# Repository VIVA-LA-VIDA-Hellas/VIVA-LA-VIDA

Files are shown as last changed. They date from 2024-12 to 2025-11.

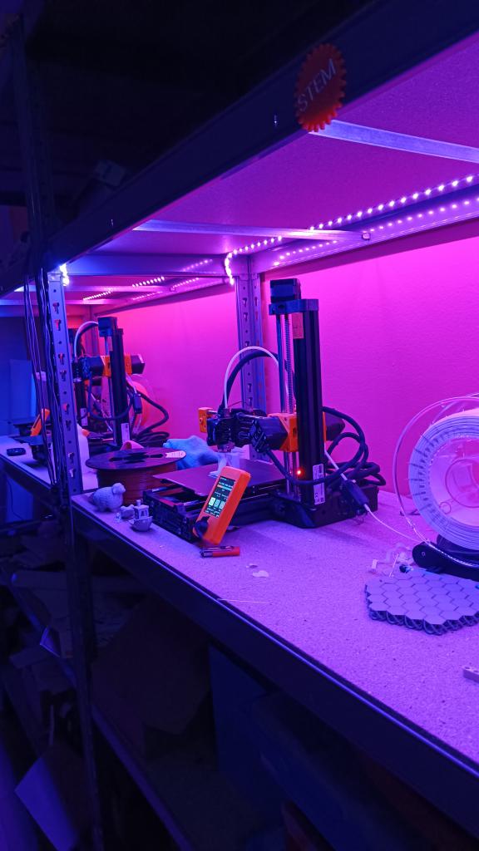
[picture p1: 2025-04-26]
3d designs/3d printed part photos/3d printing process.jpg

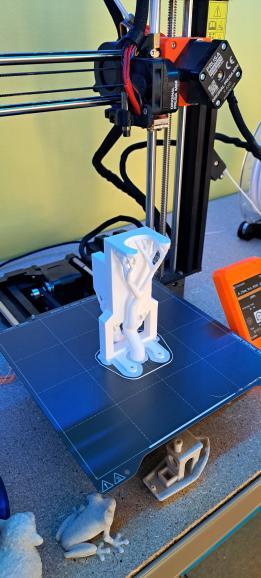
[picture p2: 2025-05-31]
3d designs/3d printed part photos/Motor base printing.jpg

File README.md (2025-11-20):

# **VIVA ΛA VIΔA** 
# $${\color{green}FUTURE \space ENGINEERS \space 2025}$$ 
> ## HELLENIC TEAM

viva la vida gif

## <ins>*Find us on:*<ins/>
Website (https://www.viva-la-vida.gr/)
Youtube (https://www.youtube.com/@VIVALAVIDAFutureEnginners)
Facebook (https://www.facebook.com/groups/1252558666360750)
Instagram (https://www.instagram.com/viva_la_vida_gr/)
TikTok (https://www.tiktok.com/@viva_la_vida_gr)

## TEAM MEMBERS:
### Nikol Vasilopoulou (user: Quart0xe)
### Panagiotis Mourmouris (user: Panos1431)
### Thanos Karatsis (user: thkaratsis)

*Disclaimer: we did not use these accounts in the creation of this repository. Instead we created a new email and github account specificaly for our team, which we all have access to and utilise across all platforms. 

# INDEX
### *Use the index for an easy navigation of our github or, continue bellow to view our creation process, as well as an overview on everything about the robot.*

## 1. Mobility management
####        1.1 [Motor](https://github.com/VIVA-LA-VIDA-Hellas/VIVA-LA-VIDA/blob/main/Vehicle/Compartments/Electronics-DC-Motor.md)
####        1.2 [Ackerman](https://github.com/VIVA-LA-VIDA-Hellas/VIVA-LA-VIDA/blob/main/Vehicle/Compartments/Ackerman%20Steering.md)
####        1.3 [Servo](https://github.com/VIVA-LA-VIDA-Hellas/VIVA-LA-VIDA/blob/main/Vehicle/Compartments/Electronics-Servo-Motor.md)
####        1.4 [Servo and motor 3d Bases](https://github.com/VIVA-LA-VIDA-Hellas/VIVA-LA-VIDA/tree/main/3d%20designs/3d%20schematics)

## 2. Power Management
####        2.1 [Batteries](https://github.com/VIVA-LA-VIDA-Hellas/VIVA-LA-VIDA/blob/main/Vehicle/Compartments/Electronics-Power%20System.md)
####        2.2 [PCB circuit designs and schematics](https://github.com/VIVA-LA-VIDA-Hellas/VIVA-LA-VIDA/tree/main/Schematics/PCB)

## 3. Sensors
####        2.1 [Distance sensors](https://github.com/VIVA-LA-VIDA-Hellas/VIVA-LA-VIDA/blob/main/Vehicle/Compartments/Electronics-Sensors-Distance.md)
####        2.2 [Accelerometre / Gyro](https://github.com/VIVA-LA-VIDA-Hellas/VIVA-LA-VIDA/blob/main/Vehicle/Compartments/Electronics-Sensors-Gyro.md)
####        2.3 [Camera](https://github.com/VIVA-LA-VIDA-Hellas/VIVA-LA-VIDA/blob/main/Vehicle/Compartments/Electronics-Camera.md)
####        2.4 [Buttons & Leds](https://github.com/VIVA-LA-VIDA-Hellas/VIVA-LA-VIDA/blob/main/Vehicle/Compartments/Electronics-Interface-and-Debugging.md)

## 4. 3D Prints
####        4.1 [3D schematics](https://github.com/VIVA-LA-VIDA-Hellas/VIVA-LA-VIDA/tree/main/3d%20designs/3d%20schematics)
####        4.2 [Photos of 3D printed parts](https://github.com/VIVA-LA-VIDA-Hellas/VIVA-LA-VIDA/tree/main/3d%20designs/3d%20printed%20part%20photos)

## 5. Pictures 
####        5.1 [Team photos](https://github.com/VIVA-LA-VIDA-Hellas/VIVA-LA-VIDA/tree/main/Team%20photos)
####        5.2 [Vehicle photographs](https://github.com/VIVA-LA-VIDA-Hellas/VIVA-LA-VIDA/tree/main/Robot%20Photos)

## 6. Performance videos
####        6.1 [Youtube channel link](https://www.youtube.com/@VIVALAVIDAFutureEnginners)
####        6.2 [All video links](https://github.com/VIVA-LA-VIDA-Hellas/VIVA-LA-VIDA/tree/main/Videos)

## 7. Daily entries
####        7.1 [Logs](https://github.com/VIVA-LA-VIDA-Hellas/VIVA-LA-VIDA/tree/main/Training%20meetings%20log)

## 8. Code files
####        8.1 [Open Challenge](https://github.com/VIVA-LA-VIDA-Hellas/VIVA-LA-VIDA/tree/main/Code%20files/1.%20Open%20Challenge)
####        8.2 [Obstacle Challenge](https://github.com/VIVA-LA-VIDA-Hellas/VIVA-LA-VIDA/tree/main/Code%20files/2.%20Obstacle%20challenge)
####        8.3 [Colour Calibration](https://github.com/VIVA-LA-VIDA-Hellas/VIVA-LA-VIDA/blob/main/Code%20files/Python%20files/New%20files%20September%2B/Colour_picker.py)

## 9. Manuals
####        9.1 [Instruction manuals](https://github.com/VIVA-LA-VIDA-Hellas/VIVA-LA-VIDA/tree/main/Instruction%20Manuals)
####        9.2 [Lego ackerman instructions](https://github.com/VIVA-LA-VIDA-Hellas/VIVA-LA-VIDA/tree/main/Instruction%20Manuals/Lego%20ackerman%20instructions)
####        9.3 [Lego differential instructions](https://github.com/VIVA-LA-VIDA-Hellas/VIVA-LA-VIDA/tree/main/Instruction%20Manuals/Lego%20differential%20instructions)
####        9.4 [Build details](https://github.com/VIVA-LA-VIDA-Hellas/VIVA-LA-VIDA/tree/main/Robot%20Photos/Descriptive%20photos)
####        9.5 [Full instructions](https://github.com/VIVA-LA-VIDA-Hellas/VIVA-LA-VIDA/tree/main/Instruction%20Manuals/Full%20robot%20instructions)

## 10. Extra material
####        10.1 [Team logo](https://github.com/VIVA-LA-VIDA-Hellas/VIVA-LA-VIDA/tree/main/Team%20-%20Extras/Logo)
####        10.2 [Team name - VIVA ΛΑ VIΔΑ](https://github.com/VIVA-LA-VIDA-Hellas/VIVA-LA-VIDA/tree/main/Team%20-%20Extras/Name)
####        10.3 [Team shirts](https://github.com/VIVA-LA-VIDA-Hellas/VIVA-LA-VIDA/tree/main/Team%20-%20Extras/Shirts)

# RESEARCH / EXPERIMENTAL PHASE

### Creating [red/green colour detection](https://github.com/VIVA-LA-VIDA-Hellas/VIVA-LA-VIDA/blob/main/Code%20files/Python%20files/R_G_cannyoutlineWORKING.py)
Using python and opencv we created a program that detects red and green objects and outputs what the computer sees in the prossess.
To do this, firstly we used colour dropping to <ins> find approximate HSV values  of obstacles and edit the ranges in our code </ins>

### $${\color{red}Red:}$$



### $${\color{green}Green:}$$



### [Colour picker used](https://pinetools.com/image-color-picker)

Using the data, we created a range where an object is detected as red or green. The full range that can be detected is min:0 , max:255
```python
    red_lower = np.array([0, 120, 70])
    red_upper = np.array([10, 255, 255])
```
```python
    green_lower = np.array([45, 160, 0])
    green_upper = np.array([100, 255, 150])
```
Then, we applied a HSV mask to separate the objects of each colour from the rest of the feed and used imgcanny to find the corners of the objects detected, using that to add an outline according to their colour (red/green)
Mask:
```python
mask_red1 = cv2.inRange(imgHSV, red_lower, red_upper)
```
Outline:
```python
    img_contours = img.copy()
    for contour in contours_red:
        x, y, w, h = cv2.boundingRect(contour)
        cv2.rectangle(img_contours, (x, y), (x + w, y + h), (0, 0, 255), 2)  # Red rectangle
```
Same for green.
> ### Green:


> ### Red:



Notice how it even detects the pile of red objects on the floor **~3m away**, We want to turn based on the closest object to the robot at any given time.
To detect that, we add limits to the size we consider an object 
> We do this so that it doesnt start turning too early or if it sees a spec of green/red in the background), its basically a filtering process that cuts down on most of the >noise.

For trials we set the minimum requirement in size (area) for a detected colour mass to be considered an object, as **500 pixels**
```python
def get_largest_contour(mask, min_area=500)
```

Next, we made it choose the largest object visible to focus on first
```python
def get_largest_contour(mask, min_area=500):
    contours, _ = cv2.findContours(mask, cv2.RETR_EXTERNAL, cv2.CHAIN_APPROX_SIMPLE)
    if not contours: return None
    largest = max(contours, key=cv2.contourArea)
    if cv2.contourArea(largest) < min_area: return None
    x, y, w, h = cv2.boundingRect(largest)
    return largest, (x, y), (x + w, y + h), w*h
```

### Updating our colour picking method
The issue with this code was that it needed calibrating in different lighting conditions, so we made out own [colour picker](https://github.com/VIVA-LA-VIDA-Hellas/VIVA-LA-VIDA/blob/main/Code%20files/Python%20files/New%20files%20September%2B/Colour_picker.py) that worked more accurately with the hsv values our camera detected. With this the obstacle detection became much more time efficient but also accurate.

Colour picker sample
```python
def mouse_callback(event, x, y, flags, param):
    global frame
    if event == cv2.EVENT_LBUTTONDOWN and frame is not None:
        bgr = frame[y, x]
        hsv = cv2.cvtColor(np.uint8([[bgr]]), cv2.COLOR_BGR2HSV)[0][0]
        print(f"Clicked at ({x},{y}) | BGR: {bgr} | HSV: {hsv}")

cv2.namedWindow("Live Feed")
cv2.setMouseCallback("Live Feed", mouse_callback)
```
We use input from our camera to our computer as a live feed, clicking on any pixel to get the HSV values the camera detects straight to our terminal.
We can then imput them straight into our colour detection limits, (red_lower, red_upper, green_lower, green_upper)

### Using what we detected to avoid the obstacles
Now that we can succesfully detect the red and green obstacles, we decided to implement a simple system for the robot to use in order to turn. 
It uses the Objects detected as a reference point and tries to rotate away from them, untill they are outside of the visible area (in other words, when they are far away enough for the robot to not collide with them).
Reminder, the robot must move **right** if it detects **red** and on the flip side, **left** when it detects **green**
> In other words, if we draw a line on the right side of the "turn right" block (red) and the left side of the "turn left" block (green), by moving toward the side it is placed on and effectively moving the entire obstacle out of our view, we manage to pass it.

So for **Green** (Turn left):

green pillar

And for **Right** (Turn right):

red pillar

### Next, we created the [Middle_Lane_Canny](https://github.com/VIVA-LA-VIDA-Hellas/VIVA-LA-VIDA/blob/main/Code%20files/Python%20files/Middle_Lane_Canny_WORKING.py)
We applied the same code from the previous program, this time switching green and red with white and black in order to diffrentiate the (white) floor from the (black) walls.
From this process, instead of outlining the walls found, we used the line they formed from edge detection on each side and <ins> calculated the middle point between the two to create a path for the robot to follow </ins>
```python
for i in range(height):
        left_avg = left_edges[i]
        right_avg = right_edges[i]

        if left_avg is not None and right_avg is not None:
            # Calculate the midpoint and draw the path
            middle_line = (left_avg + right_avg) // 2

            # Draw the path line (white) with increased thickness
            cv2.line(edges_black, (middle_line, i), (middle_line, i), (255, 255, 255), 3)  # Increased thickness
```

[You can see the output we got here](https://github.com/VIVA-LA-VIDA-Hellas/VIVA-LA-VIDA/blob/main/Videos/MIDDLE_LANE_VIDEO_COMPRESSED.mp4)

### Output image

### When we moved the inner square walls, <ins>the path to follow (middle lane) moved too</ins>


### Why we didn't end up using this code (Middle_Lane_Canny) for the first mission
Although this code worked exceptionally well when the robot was faced with long straight paths surrounded by contrasting walls, the same can't be said for turns.
When we tested it with a large camera connected to a laptop, it was facing the track from a very high up angle so it had a better view and could detect turns well.
But, when we tested multiple different cameras connected to a raspberry pi, including a fisheye camera, none of them has a scope wide enough for the current code to predict sharp turns, so the path ended up either guiding the robot straight into the wall, or, turning the opposite direction than expected.  

This wasnt working for us. The camera couldn't be as high up as it was originally when its placed on the robot -in the track- and it also needed the robot to go relatively slow so it can catch up with the camera feedback. This is fine for the second mission, where obstacle avoidance is a higher priority than speed, but for a quick first mission we had to find a new way to sense when and how much the car needs to turn.

>[!NOTE]
>The fact that this detection process didn't work for us doesn't render it unuseable. Combined with the use of a different logic specifically for turns, there is potential for a useable output but we decided to take a different approach.

### Recognising turns - Detecting Blue and Orange lines
Using the same colour picking process we created earlier, we can also detect blue and orange. Using these colours we were able to turn as well as the direction of said turn.

Example values:
## $${\color{blue}Blue}$$
```python
    blue_lower = np.array([100, 60, 80])
    blue_upper = np.array([120, 120, 170])
    mask_blue = cv2.inRange(imgHSV, blue_lower, blue_upper)
```
## $${\color{orange}Orange}$$
```python
    orange_lower = np.array([0, 110, 110])
    orange_upper = np.array([20, 160, 230])
    mask_orange = cv2.inRange(imgHSV, orange_lower, orange_upper)
```

Of course, these values have to be calibrated before the launch of every mission due to the changes in lighting conditions, but we found that this process was much more failproof so it was utilised for the second mission.

The logic of the [Blue and Orange turn detection](https://github.com/VIVA-LA-VIDA-Hellas/VIVA-LA-VIDA/blob/main/Code%20files/Python%20files/New%20files%20September%2B/Stage%202/Orange%20Blue%20detection.py) Program is as follows:

Using the HSV mask, this time with blue and orange instead of red and green, we detect the presense of those colours in the feed.
The difference between the detection comes with the shape of what we're trying to detect. Instead of the cube shaped obstacles that were being previously detected as squares, we needed to now detect lines - continuous strings of pixels with either colour.

 We detected the lines using Hough Transform
 ```python
    lines_orange = cv2.HoughLinesP(edges_orange, 1, np.pi / 180, threshold=50, minLineLength=50, maxLineGap=10)
    lines_blue = cv2.HoughLinesP(edges_blue, 1, np.pi / 180, threshold=50, minLineLength=50, maxLineGap=10)

    img_lines = img.copy()

    # Draw lines for visualization
    if lines_orange is not None:
        for x1, y1, x2, y2 in lines_orange[:, 0]:
            cv2.line(img_lines, (x1, y1), (x2, y2), (255, 0, 0), 2)

    if lines_blue is not None:
        for x1, y1, x2, y2 in lines_blue[:, 0]:
            cv2.line(img_lines, (x1, y1), (x2, y2), (0, 165, 255), 2)
 ```
We needed to track which of the two lines (If they were visible) was closest to the robot.
Since the camera output is in 2d, the **depth** that we see is changed into **height**.

<p align="center" width="100%">
    From our angle vs from the robots point of view: 
</p>
<p align="center" width="100%">
     
     
</p>

<p align="center" width="100%">
    From the robot's perpective, the line that is closer to it is also <ins> the line that appears lower on its y axis. </ins>
     
</p>

As you can see in the above image, in this specific scenario where the orange line is clearly closer than the blue one, it is also lower at the point where it intersects with the y axis.
We utilised this property in our code, but instead of using the point y=0 (midpoint) as reference, we used the pixels of our camera output.
Since when we start out camera configuration, we always set it to:

```python
picam2 = Picamera2()
picam2.configure(picam2.create_preview_configuration(main={"size": (640, 480)}))
picam2.start()  
```
So, a total of 640 pixels on the y axis and 480 on the x axis,
>[!NOTE]
>The values start at the top-left most corner where (x,y) is (0,0), Therefore when an object is detected at (example) (x,600), it is at the bottom of the screen.
>Since we want the object to be close to the robot when it turns to avoid turning too early, we set a reference point of y=400 to act as a "secondary x axis", where if orange/blue is detected above that limit (so, on the lower third of the screen), the car should turn.

For safety, we also implemented a condition to eliminate the chanse of both a orange and blue line simulatiously being found bellow the threshold, where the robot only takes into account the one which is closest to itself.

```python
        orange_y = 0
        blue_y = 0
        orange_y = y_at_center(lines_orange)
        blue_y = y_at_center(lines_blue)
 ```

*The values of orange_y and blue_y are originally set to 0 to avoid an error we encountered where the lower line was detected bellow the threshold before the further one was detected at all, returning a non valid value ("NONE") and ending the program abruptly.

```python
        if orange_y > blue_y and orange_y > 400:
            print("Turn right (orange line lower at center)")
            Turn = "Right"
            TURN_ANGLE = 120
        elif blue_y > orange_y and blue_y > 400:
            print("Turn left (blue line lower at center)")
            Turn = "Left"
            TURN_ANGLE = 60
        else:
            print("No line detected at center")
            Turn = "No"
```

Using the above logic combined with an IMU for turning, we managed to make our [imucameraturn.py](https://github.com/VIVA-LA-VIDA-Hellas/VIVA-LA-VIDA/blob/main/Code%20files/Python%20files/New%20files%20September%2B/Stage%202/imucameraturn.py) program.
> ## A program that:
> Moves forward until either a blue or orange line is detected
> Depending on which one is a) lower and b) bellow our set threshold of 400 pixels, output the turn direction (left or right)
> Steer untill the IMU detects the 90 degree change, by setting the servo angle to point left or right accordingly.

This straight-forward logic was ready to be implemented in the trials for the **second mission.**

# First mission - Final programm description

<!-- TOC -->
- [Project Overview](#project-overview)
- [Core Functionality](#core-functionality)
- [Control Logic (high level)](#control-logic-high-level)
- [Code Structure](#code-structure)
- [Hardware Setup](#hardware-setup)
- [Configuration](#configuration)
- [System Architecture Diagram](#system-architecture-diagram)
- [Mission Path Diagram](#mission-path-diagram)
<!-- /TOC -->

The program runs on a **Raspberry Pi** and offers two operation modes:
- **GUI Mode (Debug):** Visual interface with real-time plots and tuning sliders.
- **Headless Mode (Competition):** Fully autonomous execution via physical start button.

---

## Core Functionality 
- **Autonomous Navigation:**
  - Follows walls using ToF (VL53L0X) or Ultrasonic sensors.
  - Performs left/right turns based on open-space detection and front thresholds.

- **Finite-State Machine Logic:**
  - Operates under these main states:  
    `IDLE → CRUISE → TURN_INIT → TURNING → POST_TURN → STOPPED`
  - Each state manages specific motor and servo behaviors.

- **Sensor Fusion & Filtering:**
  - Combines ToF/ultrasonic inputs using median, spike rejection, and optional EMA smoothing.
  - Stabilizes readings and eliminates transient noise.

- **Yaw & Turn Control:**
  - Integrates MPU6050 gyro data for angular tracking.
  - Executes precision turns with direction locking, timeouts, and slew-limited servo control.

- **Adaptive Environment Handling:**
  - Detects narrow corridors via side-sum analysis.
  - Dynamically scales speed and correction margins for safer movement.

- **Safety & Lap Control:**
  - Instant front-stop and obstacle recheck timer.
  - Lap counting with automatic halt after the final lap.

---

## Control Logic (high level) 
- **CRUISE:** Straight motion; after 1st turn, apply timed wall-following corrections if side distance < soft margin.
- **TURN_INIT:** When `front < FRONT_TURN_TRIGGER` and lockout OK; keep straight (or gentle correction after 1st turn) while waiting for **exactly one** open side. Apply optional **direction lock** after the first decision.
- **TURNING:** Set servo to the commanded (left/right) angle; integrate gyro Z and **stop when target yaw** is reached within tolerance. Guards: timeout and max yaw.
- **POST_TURN:** Short straight stretch to stabilize, then return to CRUISE.
- **STOPPED:** Triggered by obstacle or max-laps; obstacle mode self‑retries after a wait window.

**Narrow Mode:** If `left+right` (valid readings) < threshold, scale speeds/thresholds to be conservative in tight corridors.

---

## Code Structure 

1. Imports
    - External Libraries
    - Internal Modules
2. Variables
    - Global Constants
    - Robot-Specific Variables
3. H/W Setup
    - Hardware Configuration
    - Pin Assignments
4. Robot Classes
    - Sensor Handling
    - Motor Control
    - State Management
5. Robot Loop
    - Main Control Loop
    - Decision Making
    - Movement Logic
6. GUI
    - Tkinter Setup
    - Sliders & Data Visualization
7. Main
    - Initialization
    - Robot Execution
      
---

## Hardware Setup 
| Component | Function |
|---|---|
| Raspberry Pi | Core computing unit |
| PCA9685 | Motor and servo PWM driver |
| VL53L0X ToF Sensors | Distance measurement |
| Ultrasonic Sensors | Alternative wall sensing |
| MPU6050 | Gyro for yaw tracking |
| LEDs | Status indication |
| Button | Start trigger in headless mode |

---

## Configuration 
Configuration values are defined in code but can be overridden using `1st_mission_variables.json`.
All GUI slider changes can be saved and reloaded.

---

## System Architecture Diagram 
```text
 ┌──────────────────────────────────────────┐
 │             SENSOR THREAD                │
 │  - ToF & Ultrasonic readings             │
 │  - Median & EMA filtering                │
 │  - Updates global sensor_data            │
 └──────────────────────────────────────────┘
                    │
                    ▼
 ┌──────────────────────────────────────────┐
 │            ROBOT LOOP (FSM)              │
 │  IDLE → CRUISE → TURN_INIT → TURNING →   │
 │  POST_TURN → STOPPED                     │
 │  - Yaw integration (MPU6050)             │
 │  - Servo & motor control                 │
 │  - Lap counting & safety                 │
 └──────────────────────────────────────────┘
                    │
                    ▼
 ┌──────────────────────────────────────────┐
 │             GUI / HEADLESS MODE          │
 │  - Dashboard                             │
 │  - Sliders, plots, and CSV export        │
 │  - Physical start button (headless)      │
 └──────────────────────────────────────────┘
```

---

## Run Modes 
- **Debugging (GUI) Mode:**
  Set `USE_GUI = 1` and press Start Readings & Start Loop button.
- **Competition (Headless) Mode:**
  Set `USE_GUI = 0` and press the hardware start button.

---

# BOM Bill of materials all prices for our robot compartments

## Core System
| Material | Amount | Price  |
|---|---|---|
| Raspberry Pi 5 8GB | 1 | 96.50 |
| Raspberry Pi Micro SD 64GB | 1 | 9.50  |
| Active Cooler for Raspberry Pi 5 | 1 | 6.40  |
| GPIO Ribbon Cable 40P | 1 | 2.00  |
| IDC Connector 2x20 Pin Male | 1 | 0.45  |

## Sensors
| Material | Amount | Price |
|---|---|---|
| Camera Arducam IMX219 fisheye lens | 1 | 18.92 |
| Ultrasonic Sensor HC-SR04 | 3 | 5.40  |
| Laser Sensor - VL53L0X | 6 | 28.80 |
| Triple Axis Gyroscope & Accelerometer MPU6050 | 1 | 3.60  |

## Power & Protection
| Material | Amount | Price |
|---|---|---|
| Battery Holder 1x18650 for PCB | 3 | 2.70  |
| Battery Lithium 18650 3.6V 3400mAh | 3 | 17.40 |
| Li-ion Battery Charger Protection Board | 1 | 3.40  |
| Fuse 4A | 1 | 0.71  |
| Main Power Switch | 1 | 2.23  |
| DC Power Jack 5.5×2.1mm | 1 | 0.20  |
| Step-Down Converter LM2596S | 1 | 2.90  |

## Motors & Motion
| Material | Amount | Price |
|---|---|---|
| Metal Gearmotor 25mm – 210RPM 9–12V | 1 | 6.80  |
| DC Motor Driver Board DRV8871 | 1 | 10.80 |
| Standard Servo MG996R | 1 | 8.90  |
| 16-Channel PWM/Servo Driver PCA9685 | 1 | 6.80  |

## Wiring & Connectors
| Material | Amount | Price |
|---|---|---|
| Jumper Wires 30cm 5-Pin | 6 | 2.50  |
| Molex KF2510 Jumper Wire 4-Pin | 3 | 1.20  |
| Flexible Flat Cable 0.5mm 22-Pin | 1 | 2.90  |

## PCB & Prototyping
| Material | Amount | Price |
|---|---|---|
| PCB Prototype | 5 | 26.25 |
| Tact Switch SMD | 1 | 0.08  |
| LED 0805 SMD | 3 | 0.36  |
| Resistor 0805 | 12 | 0.24  |

## Fasteners & Hardware
| Material | Amount | Price |
|---|---|---|
| M2 Plastic F/F L20mm | 2 | 0.30  |
| M2×8mm | 8 | 0.47  |
| M3×12mm Flat Head | 2 | 0.11  |
| M3×16mm Flat Head | 20 | 1.15  |
| M3×20mm Flat Head | 14 | 0.97  |
| M3×30mm Flat Head | 2 | 0.15  |
| M3×50mm | 2 | 0.70  |

##  [Complete list of all materials amounts and prices](https://github.com/VIVA-LA-VIDA-Hellas/VIVA-LA-VIDA/blob/main/Instruction%20Manuals/Materials%20needed%20and%20BOM.md)

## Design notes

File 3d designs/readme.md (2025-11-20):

# INSTRUCTIONS - HOW TO ASSEMBLE THE 3D PRINTED MECHANICAL PARTS FROM SCRATCH

## OVERVIEW

  How were the 3D-printed parts designed?
  What tools are needed for the process? 
  How can the car be assembled step by step?

## DESIGN OF 3D PARTS

All the 3D-printed components of the car were designed using Fusion 360, a powerful software that allows us precise modeling of every detail.



Throughout the development process, each part was refined repeatedly, with multiple design
iterations made to enhance efficiency, performance, and overall assembly compatibility.
This continuous cycle of testing and improvement ensured that every printed element met
the project’s functional requirements while maintaining structural integrity.

In the following photo you can see an overview of the creation process of the motorbase throughout our versioning.



Making changes to the original sketches was an essential part of achieving both efficiency and precision in the final design.
Each adjustment, whether in dimensions, geometry, or alignment, contributed to improving how the parts fit and functioned together.
These refinements not only reduced material waste and printing time but also ensured smoother assembly and more reliable performance during the car’s missions.
Through this iterative process, the design evolved from a basic concept into a well-optimized model capable of delivering consistent and accurate results.





After a series of careful modifications and refinements, the final model demonstrates an optimal balance between design accuracy and functional performance.
Each individual change, however small, contributed to a more efficient structure and smoother operation, ensuring that every component works seamlessly as part of the whole.
The result is a precisely engineered model car that fulfills its intended missions with reliability and efficiency, reflecting the success of a thoughtful and well-executed design process.

## TOOLS AND EQUIPEMENT

Using 3D printers to produce the car’s components was a logical and efficient choice, given the need for precision, customization, and consistency across all parts.
It also helps us by eliminating the need for expensive replacements in the scenario of a broken part, since we can easily print a replica at a fraction of the cost.
Additive manufacturing allowed each piece to be fabricated directly from the digital design, ensuring exact dimensions and reducing the possibility of human error.
This method also made it possible to create complex geometries that would be difficult to achieve through traditional manufacturing, while maintaining full control over material usage and production time.

> [!NOTE]
> The printers primarily used for this project were the Prusa i3 MK3S and the Prusa Mini, both known for their reliability, accuracy, and high-quality output.

6n7

To assemble the individual 3D-printed components, a combination of **screws** and **nuts** was used to ensure durable and stable connections between parts.
The assembly required the use of various hand tools, including
>
> Precision screwdrivers
>
> Allen keys
>
> Small wrenches
>
> Pliers
>
> Rulers, Measuring tapes and other measuring tools

which allowed for accurate alignment and secure fastening without damaging the printed surfaces.
This method provided both strength and flexibility, enabling easy disassembly for maintenance or adjustments when needed.
Additionally, a few small modular elements (LEGO Components) were incorporated into certain sections,
adding an extra layer of versatility and precision to the overall construction.



In addition to the main 3D-printed and mechanical components, several secondary materials 
such as **rubber bands** and **small springs** were incorporated to enhance the car’s overall stability and efficiency.
These elements played a crucial role in absorbing vibrations, maintaining tension where needed, and ensuring smoother movement during operation.
Though simple in nature, these materials contributed significantly to the model’s performance,
providing flexibility and resilience that complemented the precision of the printed and assembled parts.




# $${\color{green}INSTRUCTIONS}$$	    

## $${\color{lightgreen}How \space to \space succesfully \space replicate \space our \space robots \space 3d \space printed \space compartments}$$

## Step 1: Prepare Your 3D Printing Software

Download [**PrusaSlicer**](https://prusaslicer.net/) or another 3D printer software of your choice, then upload each model file individually.
[Click here for installation help](https://help.prusa3d.com/article/install-prusaslicer_1903)

Before assembly begins, you’ll need to prepare your parts for printing
PrusaSlicer is a reliable and easy-to-use program that allows you to view, adjust, and slice your 3D files for printing.
Simply open the software, import each part file one at a time, and make sure all components are correctly oriented and ready for your specific printer setup.

> [!TIP]
> You can find all the files you need to replicate our robot in the [3d schematics](https://github.com/VIVA-LA-VIDA-Hellas/VIVA-LA-VIDA/tree/main/3d%20designs/3d%20schematics) folder

## Step 2: Locate and Prepare the Model Files for Printing

Open the provided folder and upload each part file into your slicer software. Some parts need to be printed multiple times.

Each file has been carefully designed and tested for compatibility, so you won’t need to make any modifications.
Simply open your slicer program and load the files one by one.
Make sure to print the correct quantities for each component as listed below:

- [ ] 1× Chassis
- [ ] 1× Camera Base
- [ ] 1× Servo Base
- [ ] 3× Distance Sensor Bases
- [ ] 1× Motor Gear
- [ ] 3× Time of Flight (ToF) Sensor Bases

Double-check that all parts are correctly oriented and fit within your printer’s build volume.
Once everything looks ready, you can proceed to slicing and printing each part according to your printer’s material and settings.

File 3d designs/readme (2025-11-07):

INSTRUCTIONS - HOW TO ASSEMBLE THE MECHANICAL PARTS FROM SCRATCH!!!

It is quite remarkable to think that we can now construct a fully functional model car entirely from 3D-printed components
an intricate machine designed not merely for display, but to perform two carefully defined missions with precision and reliability.
What might first appear as a complex engineering task soon reveals itself to be an engaging and almost meditative process:
assembling each meticulously printed part, aligning the structure, and witnessing how digital design transforms into mechanical reality.
The beauty of 3D printing lies not only in its accuracy
but in its capacity to bring conceptual design into tangible form, translating digital blueprints into perfectly fitted mechanical elements.
As the car takes form, the experience becomes more than technical
it is a thoughtful exercise in creativity and focus, a fusion of innovation and craftsmanship that culminates in a model built with purpose, precision, and intent.

LET'S DO FIRST AN "HISTORICAL" REVIEW

  How were the 3D-printed parts designed?
  What tools are needed for the process? 
  How is the car assembled step by step?

THESE ARE SOME LOGICAL QUESTIONS THAT SOMEONE MIGHT HAVE

-------------------------------------------------------------

DESIGN OF 3D PARTS

All the 3D-printed components of the car were designed using Fusion 360, a powerful software that allowed precise modeling of every detail.

[photo1]

Throughout the development process, each part was refined repeatedly, with multiple design
iterations made to enhance efficiency, performance, and overall assembly compatibility.
This continuous cycle of testing and improvement ensured that every printed element met
the project’s functional requirements while maintaining structural accuracy and aesthetic quality.

In the following photo you can see the whole progress of making a certain part of the car (motorbase) while also the differnce between each stage of the progress

[photo2]

Making changes to the original sketches was an essential part of achieving both efficiency and precision in the final design.
Each adjustment, whether in dimensions, geometry, or alignment, contributed to improving how the parts fit and functioned together.
These refinements not only reduced material waste and printing time but also ensured smoother assembly and more reliable performance during the car’s missions.
Through this iterative process, the design evolved from a basic concept into a well-optimized model capable of delivering consistent and accurate results.

[photo3,4,5]

After a series of careful modifications and refinements, the final model demonstrates an optimal balance between design accuracy and functional performance.
Each individual change, however small, contributed to a more efficient structure and smoother operation, ensuring that every component works seamlessly as part of the whole.
The result is a precisely engineered model car that fulfills its intended missions with reliability and efficiency, reflecting the success of a thoughtful and well-executed design process.

---------------------------------------------------------

TOOLS AND EQUIPEMENT

Using 3D printers to produce the car’s components was a logical and efficient choice, given the need for precision, customization, and consistency across all parts.
Additive manufacturing allowed each piece to be fabricated directly from the digital design, ensuring exact dimensions and reducing the possibility of human error.
This method also made it possible to create complex geometries that would be difficult to achieve through traditional manufacturing,
while maintaining full control over material usage and production time.
The printers primarily used for this project were the Prusa i3 MK3S and the Prusa Mini, both known for their reliability, accuracy, and high-quality output.

[photo6,7]

To assemble the individual 3D-printed components, a combination of screws and nuts was used to ensure durable and stable connections between parts.
The assembly required the use of various hand tools, including precision screwdrivers, Allen keys, small wrenches, and pliers,
which allowed for accurate alignment and secure fastening without damaging the printed surfaces.
This method provided both strength and flexibility, enabling easy disassembly for maintenance or adjustments when needed.
Additionally, a few small modular elements (LEGO Components) were incorporated into certain sections,
adding an extra layer of versatility and precision to the overall construction.

[photo 8]

In addition to the main 3D-printed and mechanical components, several secondary materials 
such as rubber bands and small springs were incorporated to enhance the car’s overall stability and efficiency.
These elements played a crucial role in absorbing vibrations, maintaining tension where needed, and ensuring smoother movement during operation.
Though simple in nature, these materials contributed significantly to the model’s performance,
providing flexibility and resilience that complemented the precision of the printed and assembled parts.

[photo 9,10]

------------------------------------------------------------------------------

INSTRUCTIONS

------------------------------------------------------------------------------

You’re about to assemble your own 3D printed model car - a sleek, precision-designed miniature vehicle that’s ready for you to bring to life.
All the design and printing work has already been completed, so your task is focused on the fun part: putting the pieces together.
With a few basic tools and some careful attention, you’ll be able to assemble the car step by step without any complex measuring or modifications.
Each part has been engineered to fit precisely, making the build process simple, enjoyable, and rewarding.

Step 1: Prepare Your 3D Printing Software

Download PrusaSlicer or another 3D printer software of your choice, then upload each model file individually.

Before assembly begins, you’ll need to prepare your parts for printing
PrusaSlicer is a reliable and easy-to-use program that allows you to view, adjust, and slice your 3D files for printing.
Simply open the software, import each part file one at a time, and make sure all components are correctly oriented and ready for your specific printer setup.
Once uploaded, you can check print settings such as scale, infill, and support structures if necessary.
This step ensures that all your car parts will print accurately and fit together perfectly during assembly.

[photo 11,12]

Step 2: Locate and Prepare the Model Files for Printing

Open the provided folder and upload each part file into your slicer software. Some parts need to be printed multiple times.

You will recieve a folder containing the 3d files for the car.
Inside the folder you received, you’ll find all the 3D model files required to build your car.
Each file has been carefully designed and tested for compatibility, so you won’t need to make any modifications.
Simply open your slicer program (such as PrusaSlicer) and load the files one by one.
Make sure to print the correct quantities for each component as listed below:

1× Chassis
1× Camera Base
1× Servo Base
3× Distance Sensor Bases
1× Motor Gear
3× Time of Flight (ToF) Sensor Bases

[photo 13]

Double-check that all parts are correctly oriented and fit within your printer’s build volume.
Once everything looks ready, you can proceed to slicing and printing each part according to your printer’s material and settings.

Step 3: Construct the Differential System

Assemble the differential system using the motor base, DC motor, motor gear, and several LEGO parts, along with tie-ups and screws to secure everything in place.

.....need info.....

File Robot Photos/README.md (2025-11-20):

## Photos of our final robot
> We recomment taking a look at the [descriptive photos](https://github.com/VIVA-LA-VIDA-Hellas/VIVA-LA-VIDA/tree/main/Robot%20Photos/Descriptive%20photos) for a more in depth view of our build.
## $${\color{white}Front}$$

front

## $${\color{white}Right}$$

right side

## $${\color{white}Left}$$

left side

## $${\color{white}Rear}$$

backside

## $${\color{white}Top}$$

top

## $${\color{white}Bottom}$$

bottom

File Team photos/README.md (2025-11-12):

## Here you can find photos of our team during the competition preperation phase!!

### Team photo

team 1

### $${\color{blue}In \space order \space of \space Appearance}$$
- Nikol Vasilopoulou (Programmer)
- Panagiotis Mourmouris (3D prints and mechanical)
- Giannis Charitoudis (Coach)
- Thanos Karatsis (Electrical)

Team 2

### Shirt photo

shirts back

### Silly photos

outing!!



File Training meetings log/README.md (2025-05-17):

## Here you will find the logs written throughout the preparation phase, keeping track of our progress meeting by meeting! (mid april onwards)
### They are sorted by title in year/month/day format!
download



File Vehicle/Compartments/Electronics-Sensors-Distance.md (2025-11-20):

# Distance Sensors – Why This Combination

The selected sensor suite is engineered to provide the robot with **robust, real-time spatial awareness** under the constraints of the WRO 2025 FE environment. Each sensor category contributes different strengths: short-range precision, long-range detection, and orientation stability. Together, they form a redundant, multi-modal perception system that enables reliable autonomous navigation even in unpredictable wall placements and obstacle scenarios.

---

## 1 Distance Metering Sensors

---

## a) Time-of-Flight (ToF) Sensors – VL53L0X

Time-of-Flight sensors are used for **high-precision, short-range** distance measurement. They operate using **laser-based VCSEL emitters** and measure the time taken for light to return from a surface.

### Purpose in the Robot
- Provide high-resolution (<5 mm) distance data for **close-proximity navigation**.
- Essential for **unparking logic** during the obstacle challenge.
- More reliable on **dark, matte, or angled surfaces** compared to ultrasonics.
- Excellent in detecting narrow gaps or side distances during tight maneuvers.

### Hardware & Positioning
Six (6) **VL53L0X** modules are mounted around the chassis:
        Front
Left-Front Right-Front
Left             Right
        Back

### VL53L0X Technical Specifications
- **Sensor type:** Time-of-Flight (laser ranging, VCSEL)
- **Interface:** I²C (400 kHz Fast Mode)
- **Operating voltage:** 2.6–5 V (5 V rail used)
- **Range:** 2–200 cm (optimal precision <50 cm)
- **Resolution:** ±3 mm typical
- **Field of View:** ~25°
- **Measurement speed:** up to 50 Hz
- **Key advantage:** immune to acoustic noise and surface angle variability

---

## b) Ultrasonic Sensors – HC-SR04

Ultrasonic sensors provide **long-range detection** using acoustic pulses, complementing the short-range precision of the ToF sensors.

### Purpose in the Robot
- Detect walls and open space at distances **up to 3m**.
- Used during **cruising**, **turn decisions**, and **wall-following**.
- Redundant to ToF for improved situational awareness.

### Hardware & Positioning
Three (3) **HC-SR04** units are mounted:
        Front
Left             Right

### HC-SR04 Technical Specifications
- **Sensor type:** ultrasonic (40 kHz)
- **Operating voltage:** 5 V (with resistor divider on echo → 3.3 V GPIO safe)
- **Range:** 2–400 cm
- **Resolution:** ~3 mm
- **Beam angle:** ~15°
- **Trigger pulse:** 10 µs
- **Sampling frequency:** ~20 Hz
- **Limitations:** acoustic reflections, noise spikes, angle-dependent accuracy

### Combined Benefits (ToF + Ultrasonic)
Using both categories produces a robust hybrid sensing model:

- **Short-range precision** (ToF)
- **Long-range awareness** (ultrasonic)
- **Redundancy** when one fails due to:
  - acoustic noise
  - reflective surfaces
  - angled walls causing weak returns

---

## 3 Optional / “Not Used” Sensors

The PCB includes footprints for possible expansion modules:

- Colour sensor  
- OLED diagnostic display  
- Extra tactile button  
- Piezo buzzer  
- DIP configuration switch  
- LIDAR interface header  

These are currently **NOT USED**, but the PCB layout supports future features such as color-based decision making, on-device debugging, or long-range scanning without redesigning the hardware.

---

## Final Outcome – Sensor Roles in the Final Design

After extensive testing:

### ToF – Final Evaluation
- **Pros**
  - Excellent <30 cm accuracy  
  - Very stable readings (low noise)  
  - Resistant to dark/angled surfaces  
- **Cons**
  - Limited practical range (>30–50 cm unreliable in vertical-wall environments)

### Ultrasonic – Final Evaluation
- **Pros**
  - Reliable long-range detection (>1 m)  
  - Good for early warning of walls  
- **Cons**
  - Susceptible to noise, reflections, and angle errors  

### Final Usage
- **Ultrasonic sensors**  
  - Used during **cruising**, **turning decisions**, and **general wall-following**.  
- **ToF sensors**  
  - Used for **unparking decisions** in the obstacle challenge.  
  - Used for precise short-range calibrations.

---

## Alternative Sensors Considered

Several alternative sensing technologies were evaluated but not selected due to cost or complexity.

### 1. Infrared (IR) Proximity Sensors
- Pros: cheap, wide availability  
- Cons: poor performance in ambient light, reflective-surface errors

### 2. [Lidar](https://github.com/VIVA-LA-VIDA-Hellas/VIVA-LA-VIDA/blob/main/Vehicle/Compartments/Lidar.md)
- Pros: full 360° mapping, excellent accuracy  
- Cons: too large, too heavy, not allowed or impractical for WRO FE robot dimensions

### 3. Wheel Encoders
- Pros: accurate drive-distance estimation  
- Cons: add mechanical complexity; unreliable due to robot vibrations and tight-turn requirements

### 4. Depth Cameras (Intel RealSense)
- Pros: high-resolution 3D obstacle detection  
- Cons: expensive, high power consumption, overkill for 3×3 m field

---

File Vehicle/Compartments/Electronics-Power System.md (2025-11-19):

# For our power system we chose: Li-ion batteries
Firstly, we compared the characteristics of Lithium, Lithium-Ion, Lipo and Alkaline batteries

### Lithium batteries
>Lithium batteries are one of the most commonly used battery types. They offer the highest energy density of any other battery cell, meaning they store more energy than other batteries, such as alkaline. Lithium batteries are only sold in AA, AAA, and 9V sizes; however, their mAh ratings exceed every other non-rechargeable battery. One AA lithium battery ranges from 2,700-3,400 mAh, and will last a long time, even under heavy-use.
<ins> Pros </ins>
<ins>**Last up to 4x longer compared to other battery types
Light-weight for portable devices
Ideal for heavy-use**</ins>
Function well even in extreme temperatures, working well in outdoor devices like flashlights
Shelf life is 10-12 years; great for use in emergency devices, as the batteries will not leak or explode
<ins> Cons </ins>
Much more expensive than other battery types
<ins>**Highly flammable; require special disposal at specified locations and cannot be thrown away
Don’t come in bigger battery sizes like C or D**</ins>

### Lithium-ion batteries 
> Lithium-ion batteries (Li-ion) are <ins>**highly efficient, with a long cycle life, high energy and power density, and fast discharge capabilities**</ins>, making them ideal for portable electronics. They can last up to 15 years, significantly longer than lead-acid batteries, reducing replacement costs. These batteries typically offer 500-7000 discharge cycles before needing replacement, depending on the chemistry used. The specific energy of Li-ion batteries ranges from 100–265 Wh/kg, with an energy density of 250–693 Wh/L. Characterizing the state of charge involves extensive experiments to evaluate parameters like voltage, current, temperature, capacity, and impedance. Li-ion batteries consist of four main components: cathode, anode, electrolyte, and separator, all essential for their function. Unlike lithium cells, <ins>**Li-ion cells are rechargeable, with lifespans averaging 2-3 years or 300-500 charge cycles.** </ins>

### Lipo batteries
>The advantages of Lipo batteries are<ins> **small volume, huge capacity, light weight, non-pollution, high voltage of single cell, low self-discharging rate, more cycle times**</ins>, but its price is comparatively high.
A Lipo battery is constructed from separate cells, all connected to form the specific battery. One Lipo cell has a nominal voltage of 3.7V. When connecting these in series, the voltage increases, meaning you get 7.4V for a 2 cell battery, 11.1V for a 3 cell battery, 14.8V for a 4 cell battery etc.
Enhanced Power Density: LiPo batteries offer a slightly higher power density, which means they can deliver a burst of power more quickly. This characteristic is valuable in scenarios where immediate, high-energy output is necessary.
How long does a 5,000mAh LiPo battery last? About 25–30 minutes on full discharge. Depending on what you are using it for. A batter such as this on a remote RC car being pushed at full throttle will last about 25 minutes.
<ins> **Its chemistry leads to fire when the LiPo battery is punctured. Lithium polymer battery requires special care during charging, discharging, and storage. Li polymer battery is expensive. The cost is almost double that Li-Ion battery.** </ins>
It is commonly accepted that the preferred way to dispose of a model LiPo pack is to immerse it in a container of salt water for an extended period 

### Alkaline batteries
>Alkaline batteries are economical, easy to dispose of, and extremely popular. They normally have a<ins> **capacity rating of over 2,500 mAh**</ins>, great for moderate to heavy-use devices. Unlike lithium batteries, almost every standard size battery offers an alkaline construction, making it perfect for most devices.
<ins> Pros </ins>
Great price for quality
<ins>**Last longer due to potassium hydroxide construction**</ins>
Shelf life is 5-10 years
Function well even in extreme temperatures, working well in outdoor devices like flashlights
Lead, mercury, and cadmium-free is good for the environment, and the batteries don't need to be disposed of in a specific way
<ins> Cons </ins>
<ins>**Heavy and bulky, without additional voltage
May not work well in high drain devices
Will sometimes leak, causing the device to become unusable**</ins>

### In the end we found that:
"If you are looking for the highest voltage under load (punch or top speed) then choose a LiPo. If you are looking for the highest capacity for the weight (energy density), choose Li-ion. If safety is a big concern, then choose Li-ion."
Additionally, they offer us the required voltage, they have a capacity of 2500-3500mAh and are safer than Li-Po
**And therefore we chose <ins>Li-ion</ins> for our vehicle.**

> [!IMPORTANT]
> ### Just because the Li-ion batteries were the best fit for us, doesn't neccessarily mean they'll be the best fit for everyone.
> ### Depending on your builds requirements and needs, you can utilize any of the above batteries as <ins>alternatives</ins>.

*Characteristics*
>The system is powered using three (3) Li-ion 18650 batteries connected in series (3S), that offer us up to 12.6V when fully charged. This layout ensures an abundance of electrical power for the operation of our system.
>
>For **protection** we utilised a Charger Protection Module 3S 10A which offers us:
>- Overcharge protection (Stops from overloading)
>- Over-discharge protection (Interrupts sudden voltage drops that might hurt the batteries)
>- Short-circuit protection (As the name suggests, stops the system and batteries in case of short-circuiting)
>This specific module can provide a maximum continuous flow of 6-8A, an amount suitable for safe power distribution to the Raspberry Pi 5 and its peripherals.
>We also used a DC-DC Converter module Step-Down (5V/3A), based on the LM2596S. It has a voltage range of 3.2V - 40V (Input) and 1.3V - 35V output with a maximum of 3A.
>All of the above combined with the small size of the placket make it ideally suitable for our build

*Compatability*
>An external power jack lets us power or charge the robot without opening the chassis or disconnecting the battery, which makes
maintenance much easier

*Requirements*
> We used 3 18650 Li-ion cells in series (3S), a BMS, a main switch, a 4 A fuse and an LM2596 buck converter that generates a stable 5 V rail
> It was necessary to keep the batteries contained in a plastic sealed box when not in use to avoid danger due to flamability.

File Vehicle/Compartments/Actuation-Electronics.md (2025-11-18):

# Actuation Electronics

## 1 PCA9685 – 16-Channel I²C Servo Driver

The **PCA9685** is used to generate precise, stable PWM signals for servos and other actuators. It offloads timing from the Raspberry Pi and provides highly accurate pulse control.

### Technical Specifications
- **16 independent PWM channels**  
- **I²C communication** (up to 1 MHz Fast-Mode Plus)  
- **12-bit resolution** (4096 steps)  
- **Frequency range:** 40–1000 Hz  
- **Logic level:** 3.3 V (Pi-compatible)  
- **Output power for servos:** servo rail powered at **5 V**  
- **On-chip oscillator** for autonomous pulse generation

### Why We Use the PCA9685
- Provides **stable, jitter-free** servo pulses  
- Raspberry Pi no longer needs to generate real-time PWM  
- 16 channels offer large expansion headroom:
  - Main steering servo  
  - Additional servos for future mechanisms  
  - LEDs or other PWM devices  
- Clean separation between **logic (3.3 V)** and **servo power (5 V)**  
- Allows the robot to maintain steering precision even under heavy CPU load (OpenCV, sensor fusion)

### PCB Integration
- Connected via the **I²C bus** (shared with ToF sensors, IMU, etc.)  
- Servo power supplied from a dedicated **5 V high-current rail**  
- Ground plane shared for stable reference  
- Steering servo plugged into **Channel 0**, leaving 15 channels for future expansion

---

## 2 Benefits of This Dual-Driver Architecture

- **Dedicated high-current path** for the drive motor (DRV8871)  
- **High-precision PWM generation** for steering (PCA9685)  
- **Reduced CPU overhead** on the Raspberry Pi  
- **Electrical isolation** between motor noise and servo signals  
- **Easy swapping** of motors and servos during competition  
- **Scalability** for additional mechanisms without redesigning the board  

---

## 3 Alternative Driver Solutions Considered

### 1. Raspberry Pi GPIO Softw

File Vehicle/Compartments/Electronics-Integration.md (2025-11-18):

# System Integration and Design Philosophy

The robot’s electronics and architecture follow a cohesive design philosophy that prioritizes reliability, serviceability, clear signal integrity, and modular expansion. The guiding principles below ensure that the system remains easy to debug, easy to extend, and electrically robust during competition conditions.

---

## 1 Core Design Principles

---

## a) I²C as the Primary Sensor Bus

Most of the robot’s smart peripherals communicate over **I²C**, including:

- Time-of-Flight sensors (VL53L0X)  
- IMU (MPU6050)  
- PWM controller (PCA9685)  
- OLED display  
- Colour sensor  

### Advantages of using I²C as the backbone:
- **Two-wire simplicity** (SDA + SCL) greatly reduces wiring bulk.  
- Supports **multiple addressable devices** on the same bus.  
- Easy to add/remove modules without major code changes.  
- Long-standing Python library support on Raspberry Pi.  
- Low electromagnetic noise compared to high-frequency PWM or serial lines.

The approach keeps sensor management unified and predictable across the system.

---

## b) Separation of 5 V and 3.3 V Domains

The Raspberry Pi operates entirely on **3.3 V logic**, while many peripherals require **5 V power**. The design ensures strict protection of the Pi’s GPIO pins:

### Measures taken:
- **Resistor dividers** on ultrasonic echo pins  
- **I²C-level compatibility** enforced via 3.3 V pull-ups  
- Sensors powered from the **5 V rail** but interfacing through safe logic levels  
- Dedicated **DC-DC converter** to supply clean 5 V to all peripherals

### Benefits:
- Prevents accidental overvoltage damage to the Pi  
- Ensures consistent logic-level matching  
- Improves system electrical isolation and reliability  
- Allows mixed-voltage sensors without redesigning the core controller  

This separation keeps the digital electronics robust during rapid load changes from motors and servos.

---

## c) Clearly Labelled and Accessible Connectors

All external connectors follow a **consistent pin layout**, with clear silkscreen labels:

- Ultrasonic sensor headers  
- ToF sensor ports  
- Motor terminals  
- LIDAR expansion header  
- Servo/PWM output block  
- Power rails and test points  

### Benefits:
- Enables **fast assembly and repairs** during competition  
- Easier troubleshooting under time pressure  
- Reduces wiring mistakes  
- Ensures modular swapping of failed sensors or drivers

This is especially valuable during WRO events where quick maintenance is crucial.

---

## d) Expansion Pads for Future Upgrades

The PCB includes extra breakout pads for additional signals and modules:

- Spare GPIO  
- Additional I²C connection points  
- Extra 5 V / GND taps  
- Pads for optional components (buzzer, DIP switch, secondary sensors, etc.)

### Benefits:
- Future-proof design  
- Enables feature additions (mapping, telemetry, more sensing) without redesigning the PCB  
- Allows rapid prototyping of new ideas  
- Supports scaling the robot’s architecture over time  

Expansion capability ensures that the same base board can support multiple revisions of the robot.

---

## 2 Overall System Integration Benefits

These design choices collectively provide:

- A **clean, maintainable wiring architecture**  
- Robust protection for sensitive 3.3 V logic  
- A unified communication backbone (I²C)  
- Clear organization of power, control, and sensor domains  
- High reliability during continuous movement, vibration, and electrical load changes  

The result is a system that is not only technically solid but also easy to service and extend.

---

## 3 Alternative Design Approaches Considered

### 1. Using UART/SPI for all sensors
- **Pros:** higher speed, dedicated channels  
- **Cons:** more wiring, fewer addressable devices, less flexible for hot-swapping modules  

### 2. All-5-V sensor ecosystem
- **Pros:** simplifies power rail management  
- **Cons:** requires level shifting for the Raspberry Pi, reduces library compatibility  

### 3. Integrated motor driver + sensor board (single PCB)
- **Pros:** very compact  
- **Cons:** harder to debug or replace components individually  

### 4. CAN bus or RS485 for long-distance robustness
- **Pros:** industrial-grade communication  
- **Cons:** unnecessary complexity for a small WRO robot  

---

## Summary

The system’s integration philosophy emphasizes **simplicity, modularity, electrical safety, and expandability**. By combining a clean I²C architecture, safe logic-level separation, clearly marked connectors, and future expansion pads, the design ensures the robot remains reliable today while staying adaptable for future upgrades and new competition requirements.

---

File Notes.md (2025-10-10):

[ ] Add wro rulebook
[ ] develop main
[ ] put photos of sensors/ compartments used whenever mentioned (esp logs)
[ ] Make a pdf with mechanic and 3d printed compartments
[ ] flow chart
[ ] Create instructions for user assembly, including step by step instructions for how to install vscode/pycharm, linking websited to buy our pcb board etc
[ ] Reorganisation of old folders, final fixes
[x] rename code files

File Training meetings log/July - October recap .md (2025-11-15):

> Thursday 2nd of October 2025

# Recap July - October 

### After the summer holidays ended, we had a plethora undocumented meetings, during which we managed to replace most of the car compartments from the previous versions with our own original 3d printed compartments.
### The compartments we 3d printed are listen bellow

> Base for differential and motor
> 
> Chasis
>
> Base for TOF (time of flight) sensors
>
> Ultrasonic sensor (updated)
>
> Camera base (updated)
>
> Servo base

### Additionally, we changed our servo to a model that can withstand more force, due to the previous ones often breaking

> Old servo -> SG90
> 
> 
> 
> 
> New servo -> MG996
>
> 
> 

### We also changed our motor to a more powerfull one, editing the bases to match the new and improved version.

### On the programming side there were many updates to the previously working code for the first mission, mostly changes due to different libraries being used for the new servo. Specifically, we replaced the previous adafruit servokit and motorkit libraries for the adafruit pca9685, combining the movement of the two.

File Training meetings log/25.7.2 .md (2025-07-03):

> Wednesday 2nd of July 2025

# Updates:

We finished the design of a 3d printed base for the HC-SR04 ultrasonic distance sensor.
Half of the the chassis has already been printed and will be modified in order to match the PCB design.
Additionally, we completed designing the schematic for the PCB and moved onto its materialization.
We payed special attention to the connections between each module/component needed to function.

# Photos
a) PCB -First version design using [EasyEDA](https://easyeda.com/)

PCB

b) PCB - Top side

top layer pcb
top layer

c) PCB - Bottom side

Bottom layer Pcb (2)
Bottom layer (2)

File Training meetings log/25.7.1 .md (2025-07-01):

> Tuesday 1st of July 2025

# Updates:

We began the creation of a new 3d Printed chassis in order to have a backup robot base.
We also succesfully designed the first version of our first PCB schematic/layout - The design started off on a whiteboard but was then moved to an EDA software for the creation of an official version.

# Photos

a) 3d print design (Including the screw points)

3d distance base side 1
3d print screw connections

b) PCB whiteboard design

pcb design whiteboard

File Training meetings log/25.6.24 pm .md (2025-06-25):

> Evening of Wednesday 24th of June 2025

### We met up with parents to discuss further steps in the competition and took group photos on the track.
 - We also went out for burgers afterwards (Team bonding)

# Photos

c) Track photobomb

panos pista

d) Going out!

outing!!

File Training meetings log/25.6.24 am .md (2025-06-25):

> Morning of Wednesday 24th of June 2025

# Updates:

Since the robot started effectively looping around the track, the next step is to include the ability to detect if it is going clockwise or anti-clockwise. 
To do that we experimented both with the colour sensor, building a new base for it to screw under our robot and untill its correct callibration we also made a backup where it uses the side distance sensors to detect the first big gap, indicating the turn direction. 
Additionaly, we sketched out an aproximation of what each of the three sensor views during an anti-clockwise turning run.

# Photos

a) Colour sensor values (Blue is highlighted)

values colour sensor

b) colour sensor view (Under and front)
colour base under
colour base side

c) Distance sensor sketch
> Inner box - inner sensor (left)
> 
> Outer box - outer sensor (right)
> 
> Bottom left - front sensor values

### Flip image horizontally for clockwise values

sensor sketch

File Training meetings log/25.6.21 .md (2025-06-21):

> Saturday 21st of June 2025

# Updates:

The colour sensor was reattatched to the main body after some edits made during the previous session due to faulty wire connections, as well as coming to a total of three ultrasonic distance sensors to cover both left and right sides and front for later versions.
We used Only the left sensor to start with and created a pid program to stay within 20cm distance of the inner wall
[pid_distancesensor.py](https://github.com/VIVA-LA-VIDA-Hellas/VIVA-LA-VIDA/blob/main/Code%20files/Python%20files/pid_distancesensor.py)

### [A video of it running succesfully is linked here](https://youtube.com/shorts/GeQqc4MKFQo?feature=share)

# Photos

a) Placket creation combining the 3 distance sensors

3 sensors

b) 3D print design [snippet video of print process here](https://youtube.com/shorts/2Z2sEL-jba4?feature=share)

3d print

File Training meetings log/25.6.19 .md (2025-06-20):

> Thursday 19th of June 2025

# Updates:

Our session was spent editing the code for the first mission, specifically we made an attempt to use the camera to detect the order of the orange/blue lines at the start, using that as an indication of the direction it is to follow.
Additionally, we combined that detection -which was made using the base of the red-green detection we made a while ago- with the main program. (middle lane detection combined with distance sensor to see the front distance from the walls, indicating a turn)

# Photos

a) Robot vision (ft, the robot)

robot vision

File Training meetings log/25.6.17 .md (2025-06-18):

> Tuesday 17th of June 2025

# Updates:

We updated a placket to use on the raspbery pi4 so we can commence trials once more for the first mission. The camera detection worked well, but since we had to factory reset the device previously due to errors, we needed to redownload all libraries, of which the circuit python lib did not wish to cooperate.
We took some measurements for a new base for our distance sensor and also some colour measurments in an attempt to detect the direction of the robot (clockwise or anti clockwise) using only the camera.
Additionally, we added an ultrasonic sensor (HC-SR04) to detect the correct moment for turns, which measured extremely precisely and will move to the next versions of our robot.

# Photos

a) Middle lane detection working (Average path to follow)

middle lane

b) Workspace / Placket

workspace placket

c) 3D print (Base for distance sensor)

3d print

d) Screenshot for colour measurement (orange-blue)

20250617_14h00m16s_grim

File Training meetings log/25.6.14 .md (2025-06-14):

> Saturday 14th of June 2025

# Updates:

Firstly, we ensured that our distance sensors weren't pointed at an angle since it accumulated to a misstarget of the walls and the feedback that was returned to us from them was much larger than the actual distance between the sensors and the walls.
Second, we created a lego base to raise the front distance sensor higher as to also improve its accuracy.
We used zip ties to secure the lego in place, connecting them directly through the pieces.

# Photos

a) lego base prototype (front sensor)

prototype raising lego

b) Next base version (top side)

base top side

c) Next base version (bottom side)

base bottom side

d) Measuring distances

measuring distances

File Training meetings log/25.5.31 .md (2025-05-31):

> Saturday 31st of May 2025 -Today is also my birthday :) (Nikol)
# Updates:

Today we spent our time deciding on further steps.
We chose to build moreso on the first version of the robot compared to the lego ones due to time pressure, so we made an effort to rearrange the compartments of the robot in order to better suit our needs (eg the 3d printed motor base didnt fit when combined with the lego differential)
We made a placket but didn't end up using it since it didn't end up meeting our needs.
Additionally more changes where made to the design of the holders for the colour sensors.

# Photos

a) Robot reconstruction

robot reconstruction

b) Colour sensor base edits

colour sensor new bases

c) Soldering the placket

soldering

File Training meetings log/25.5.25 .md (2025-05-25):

> 25th of May 2025
# Updates:

Today we worked with the original version of the robot since the lego one was in the process of charging and the newest one is still being created.
Another wire on the placket got loose and inevitably cut at a certain point so we had to once again edit that arrangement.
We added an MPU and also re stabilized the distance and colour sensors which where starting to seperate form the build. 
Some edits where also done to a program we made to follow the inner wall of the track as to follow it closer and for 11 turn-forward movement repetitions not including the first turn, therefore simulating the first mission requirements of three laps.

# Photos

a) Adding parts to placket

adding parts to placket

b) sensor stabilisation

sensor stabilisation

c) Editing code

code edits

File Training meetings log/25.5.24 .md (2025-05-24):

> 24th of May 2025
# Updates:

Todays session was heavily based on coding the first mission and debugging used up most of our time since we carefully skimmed through any errors in order to ensure that it would run smoothly.
We also made a flow chart of the first mission to implement it through code.

Trials were done on the previous lego version of the robot, although it utilized an older version raspberry pi and will be changed in the future to run faster.

Additionally, we continued creating the new lego base from yesterday with more edits on the never ending 3d base versions...

# Photos

a) Debugging on robot

debugging

b) debugging on screen 

debugging computer

c) 1st mission flow chart

flow chart

d) building the new robot base

building new robot

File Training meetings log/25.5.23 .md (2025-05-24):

> 23rd of May 2025
# Updates:

### 3D printing
The 3d printing of the base finalized and was good to go after adding some small lego bits for stabilisation (so tha it wouldn't bend and inevitably snap). 
We reprinted the gear so that it was a perfect fit for the motor (It literally doesn't budge one bit when trying to remove it)

### Lego robot v2
Issues with previous lego robot
>  - Not enough space for the 3d base-lego differential, would need major shifts to incorporate them
>
>  - The placket we used lost signal from time to time
>
>  - There was no room for the camera

For all the above reasons plus our desire to always have a backup, we decided to keep that version as is and create another lego robot mirroring parts of the previous one while using the hardware components of our original -non lego- robot (raspberry pi, sensors, placket, batteries etc)

# Photos

a) Finished new motor base with lego "cage"

lego motor base cage

b) lego differential that is now dirrectly under and attatched to the 3d printed motor base

lego differential

c) New extremely stable 3d printed gear

3d printed motor gear

d) work enviroment

work envviroment

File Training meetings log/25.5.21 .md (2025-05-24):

> 21st of May 2025

# Updates:

We had a shorter meeting, therefore we spent the majority of our time focusing on finding a way to connect our 3d printed motor base with lego so that it can be readily connected to our second robot.
Additionally, we connected to it the lego differential (as mentioned before borrowed and edited from the lego G-Wagon set)
Since the motor has to connect to the lego gears on the differential, we also 3d printed a gear to serve that purpose, although the inner circle radius (cutout) was slightly larger than we wanted it.
On the topic of 3d printing, while connecting the base with the lego differential, we realised the weight of the motor caused the base to bend and make contact with the lego therefore rendering it almost unable to turn, so we started a new print with a small cutout in the specific area that was creating the issue.

# Photos

a) taking measurments 

taking measurements

b) 3d printed motor base edits

3d print edits motor base

c) Workspace ft: Lego and 3d print concauction 

workspace

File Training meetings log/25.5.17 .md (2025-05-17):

> 17th of May 2025
# Updates:

We finished the cable management on the new robot we created during the previous meeting and booted it up for trials - so far it is working as expected without the movement of pieces.
The oled screen we have on the placket shows 
> - CPU load
> - Memory usage
> - Disc usage

Additionally, we ran some more tests on the previous model of the robot and continued trying to fix the issue with the sensor I2C addresses coliding but to no avail yet.
Nevertheless it behaved better than previously on the track up to the moment it collided with the wall.

# Photos

a) Old robot 

old base

b) New robot

new base

c) Showdown between the two (Cue the cowboy music)

new vs old robot

d) Working OLED display screen

oled display screen working

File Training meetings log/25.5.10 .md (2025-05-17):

> 10th of May 2025
# Updates:

We once again changed the cable managment placket to a slightly larger one as to ensure no short circuit/discontinuity would happen since we added additional wires overwhelming the previous one.
We changed the colour sensor we where using from LSM6DS3 to TCS34725 to ensure faster more reliable results (as proven from our tests with the new sensor)
In the prosess of trying out the new colour sensor we also improved the general sensor algorythm including the two distance sensors and ran into an issue where the I2C adress of the combined distanse sensors and colour sensor coincided and would stop working when the address was altered.

Finally and most importantly, we started creating a new robot based on the needs of the previous one using a lego base combined with the hardware used previously (LION 18650 batteries with base and voltage regulator, raspberry pi 4/5 etc) while also soldering on 5 leds ( 3 smaller ones for general trials and two larger red/green ones for the second mission). Finally we 3d printed a piece to securely attach the motor to the legos and only the cable connections & managment remains. This process was fairly easy since we already have a good knowledge (after much trial and error) of the key components we are most likely going to use and therefore only needed to replicate the previous build and connections onto a different scale.

# Photos

a) Thanos fighting the sensor bugs

workspace thanos

b) Battery layer on new robot including the voltage regulator and safety against short circuits

battery layers

c) LEDs for signaling 

leds new lego base robot

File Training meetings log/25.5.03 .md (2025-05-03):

> 3rd of May 2025
# Updates:

We printed connecting pieces to stabilise the portion of lego we borrowed (ackerman) with the wheels of our robot,
The first print was too small on the wheels side (robot) while being too large for the axle side (lego)
The second was satisfactory on the robots side but not so much on the axle side (too loose this time)
Third print was near acceptable but we decided to print it a fourth time for safe measure.
On the programming/hardwiring of the robot, we had difficulty restarting the system every time for tests so we added a physical button to stop the program. Also fixed some connection issues with the placket we made for cable management previously.

# Photos

a) Axle rendering 

axle creation

b) Finished 3d print design

3d print axle

c) Placket updates

cables on placket

d) Button addition

button

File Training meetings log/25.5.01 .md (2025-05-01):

> 1st of May 2025
# Updates:
Today we had a lighter day due to it being a national holiday.
We completed the 3d printing of the camera base that was designed previously, but the screw holes for the camera
needed a bit more distance so we got to work and redisigned it to fix the issue.
Additionally, the wire connecting the fisheye camera to the microbit 4 was too short for the new camera base
design, so we switched the raspberry 4 to the raspberry 5 (which we had a longer wire).

# Photos

a) short wire issue with the rapberry pi 4

short wire

b) raspberry pi 5

rasp5

c) Longer wire fix with pi 5

long wire rasp5

d) removing the wheels to work on

wheel removal

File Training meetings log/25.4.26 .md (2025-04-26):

> 26th of April 2025
# Updates:

Re stabilised the camera holder with optimal screws
Tried to run the robot on the track ran into weight issues
Fixed errors and experimented on the above with the help of our teacher
Worked on 3d printing an entirely new camera base since it was still slightly wonky 
Large revamp of github repository, added more photos, new organisation folders
and missing information/reorganisation of existing folders

# Photos

a) workspace + robot

Workspace

b) 3d camera base (unfinished)

3d camera base

c) Github editing

github

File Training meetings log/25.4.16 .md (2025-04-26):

> Wednesday 16th of April 2025
# Updates:

We analyzed the next steps we need to take for the completion of the first misson.
Drew out the robot electrical compartments to further our understanding of them.
Worked on getting the servos to move with a command from microbit.

# Photos
a) Whiteboard sketches showcasing the compartments of the robot (Top Half) and depiction of the first mission on the track (Bottom Half)

490987320_1386252399462149_3145449555404861305_n

b) Drawing of us -nikol :)

491001894_3748701728606758_1601407522279515640_n

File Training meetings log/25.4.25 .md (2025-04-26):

> 25th of April 2025

# Updates:

Finalized the 3d printed motor base, photos include all 4 versions side by side comparison.
Tested it out on the robot and made adjustments.
Finished the deconstruction of the lego car, isolating the necessary compartments of the differential.
Improved the code for turn recognition specifically, by connecting the gap between the two paths as smoothly as possible.
Used the improved program and started the construction of a newer version with an added a red line to indicate the average of the path the robot needs to follow.
in order to have a reference point that the robot tries to center (thus controling the steering to keep it in the correct position).
Fixed the error where wires moving stopped the flow of the program by soldering with a prototype board that goes directly on the raspberry.

# Photos

a) Wires soldered onto the placket - Finally improved cable management

placket

b,c) Side by side comparison of the versions of the 3d printed servo motor base

4 versions 3d print
4vs front view

d) Lego differential

differential lego

e) Warping of fisheye camera 

Mini panos camera

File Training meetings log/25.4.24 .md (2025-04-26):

> 24th of April 2025
# Updates:

Worked on improving errors during turn recognition on the middle lane canny program, specifically seeing turns as gaps instead of continuous track. Furthermore we used spare parts to enhance the build (screws to stabilize camera and raspberry pi).
We then started to deconstruct a lego vehicle to use part of it as a prototype differential for the back wheels of the car.
Started testing the robot movement by combining the servo movement programs with the middle lane canny program 
in order to follow the path created by it.
Discovered new errors due to the low height of the camera and the movement of wires to fix during the next meeting...

# Photos

a) Error where corners weren't recognised by the program

Middle lane straight

b) Slight improvement of the above

Middle lane corner

c) Lego car base and spare parts we tested to find the right fits for the camera stabilization etc

Spare parts

d) Soldering wires to a placket

Workspace

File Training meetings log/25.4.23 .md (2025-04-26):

> Wednesday 23rd of April 2025

# Updates:

Tested out the combination of the middle_lane_canny with the movement of the
servo motors in an attempt to begin trials for the first challenge. 
We all Tested the robot on the track, experimenting with different cameras as well as using diy 
solutions to fix conectivityissues such as taping down wires and using extra screws to stabilise
the camera even further.
Also further improved the 3d print design of the servo motor base.

# Photos

a,b,c) Stabilising the camera with spare screws and sticking down wires (diy cable managment)





d) Next version of servo base (Broken)



e) Panagiotis..



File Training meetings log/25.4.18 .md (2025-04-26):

> Friday 18th of April 2025
# Updates:

Renewed and updated system on raspberry pi, including downloading missing libraries and testing
different enviroments such as vscode.
3d printed a base for the servo motor.
Connected several cameras to pi in an attempt to run the camera programs which previously didn't 
run outside of terminal, found solution by using a combination of opencv and picamera library.
Tested and aproved changes with multiple cameras and recieved satisfactory feed.

# Photos

a) Moment when 3d printing of the base was finished



b) Experimenting with thonny and vscode enviroments



c) Aerial view of the three of us :)



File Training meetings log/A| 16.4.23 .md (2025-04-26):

# Updates:

# Photos
490987320_1386252399462149_3145449555404861305_n
491001894_3748701728606758_1601407522279515640_n

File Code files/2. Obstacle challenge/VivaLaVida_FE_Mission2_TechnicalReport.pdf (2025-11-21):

# Viva La Vida — WRO FE Obstacle Challenge

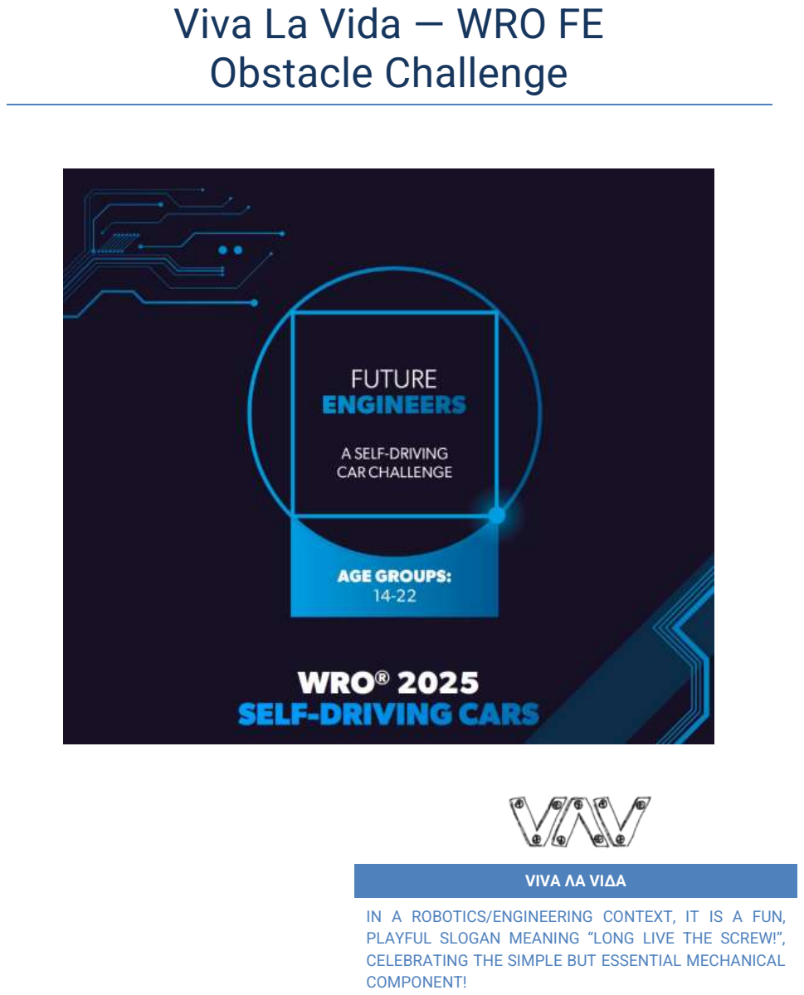
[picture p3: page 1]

VIVA ΛA VIΔΑ

IN A ROBOTICS/ENGINEERING CONTEXT, IT IS A FUN, PLAYFUL SLOGAN MEANING “LONG LIVE THE SCREW!”, CELEBRATING THE SIMPLE BUT ESSENTIAL MECHANICAL COMPONENT!

VivaLaVida
WRO 2025 Future Engineers 2 nd Mission (Obstacle Challenge)

Technical Design & Validation Report

### Table of Contents

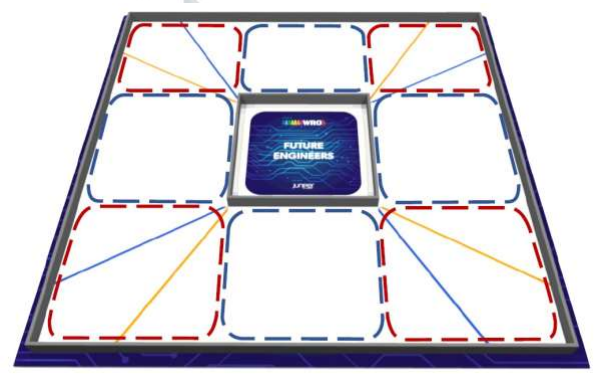
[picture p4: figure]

Technical Design & Validation Report - 1

### 1 Overview & Scope

Mission: Autonomously complete three (3) laps on the official Obstacle Challenge track while respecting randomly placed red and green traffic signs and finishing with a parallel parking manoeuvre inside the parking lot. The robot must decide on which side of the lane to drive based on the colour of the pillars and must avoid moving them. After three laps, it has to locate the magenta parking lot and perform a controlled parallel park.

The game field is a fixed-width racetrack divided into straight sections and corners. At predefined “seats” along the straights, red or green traffic signs (50×50×100 mm pillars) can be placed before each round. A red pillar instructs the vehicle to keep to the right side of the lane, while a green pillar instructs it to keep to the left side. The vehicle must not knock over, push, or significantly displace these signs during its run.

After the third lap, the objective changes from lap-time to precision: the robot needs to detect the magenta parking lot limitations and execute a parallel parking manoeuvre so that the car is fully inside the parking area and aligned with the parking borders.

Our solution reuses the same core hardware platform as in the 1st mission (Raspberry Pi, IMU, ultrasonic/ToF distance sensors, steering servo, DC motor), but adds a camera-based perception pipeline. Computer vision is responsible for lane and traffic-sign detection; the distance sensors and IMU provide safety, collision avoidance, and yaw-based heading control. A finite state machine (FSM) coordinates all behaviours: lap driving, sign handling, obstacle avoidance, parking search, and the parking manoeuvre itself.

### 2 The robot - Hardware & Wiring

### 2.1 Bill of Materials

Component | Role | Interface/Notes
Raspberry Pi | Main controller | GPIO/I²C
PCA9685 | Servo + motor PWM | 50 Hz PWM; I²C
MPU6050 | Gyro-Z for yaw | I²C
Ultrasonic x3 | Front/Left/Right | Trig/Echo via gpiozero
VL53L0X (opt.) | ToF sensors | I²C + XSHUT addressing
Steering Servo | Single | 1000–2000 µs pulse
Motor + Driver/ESC | Single | PWM ch1/ch2 (FWD/REV)
Start Button | Headless start | GPIO20
Status LEDs | Green / Red | GPIO19 / GPIO13
Battery/Power | 5–6 V servo; 5 V logic | Common ground

### 2.2 Pin Map

Subsystem | Signal | Pin/Channel | Dir | Notes
Start Button | START_BTN | GPIO 20 | IN | Pull-up; active LOW
LEDs | GREEN/RED | GPIO 19 / 13 | OUT | Status/ready
US Front | TRIG / ECHO | 22 / 23 | OUT / IN | max_distance, queue_len
US Left | TRIG / ECHO | 27 / 17 | OUT / IN | max_distance, queue_len
US Right | TRIG / ECHO | 5 / 6 | OUT / IN | max_distance, queue_len
Servo | SERVO_CHANNEL | PCA ch 0 | PWM | Steering
Motor | MOTOR_FWD / REV | PCA ch 1 / 2 | PWM | Duty 0–100%
I²C | SCL / SDA | board.SCL / board.SDA | — | PCA/IMU/ToF
ToF XSHUT | L/R/F/B/LF/LR | D16 / D25 / D26 / D24 / D8 / D7 | OUT | Addr 0x30/31/32/33/34/35

### 2.3 Robot photos

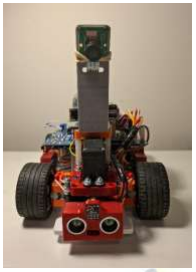
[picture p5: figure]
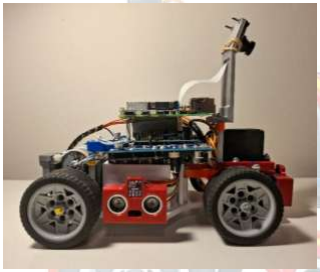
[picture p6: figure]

### 3 System Architecture

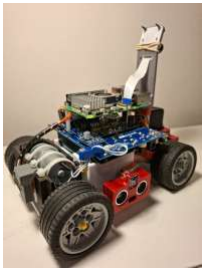
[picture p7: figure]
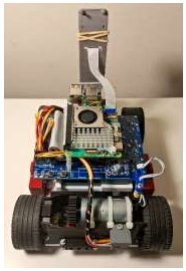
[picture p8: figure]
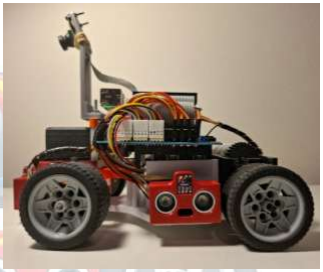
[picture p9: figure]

The Obstacle Challenge solution is implemented as a single Python program running on a Raspberry Pi. It builds on the same electromechanical stack as the 1st mission (PCA9685 for servo/motor PWM, MPU6050 IMU for yaw, ultrasonic/ToF for distances), and extends it with a camera module for lane and traffic-sign detection.

At a high level, the architecture is divided into three layers:

1. Perception Layer
- Camera & Computer Vision
- PiCamera2 captures RGB frames at a fixed resolution and frame rate.
- OpenCV converts frames to HSV colour space and extracts:
- Blue/orange lane markings on the mat.
- Red and green traffic signs (pillars).
- Magenta parking lot limitations.
- Range & Pose Sensing
- Ultrasonic and/or VL53L0X ToF sensors measure front, left, and right distances.

- An MPU6050 IMU provides gyro-Z data, integrated into yaw (relative heading) for turn and heading control.
2. Decision & Control Layer
- A finite state machine (FSM) maintains the current high-level mode:
- Lap driving (following lane and obeying traffic signs).
- Obstacle handling (stop / slow-down in front of unexpected objects).
- Parking search (after lap 3).
- Parking alignment and execution.
- The FSM uses:
- Vision features (lane centre offset, sign type/position, parking markers).
- Distance thresholds (safety margins and stop distance).
- Yaw targets (for consistent cornering and straight-line recovery).
- The controller outputs:
- Steering commands (servo angle).
- Speed commands (PWM duty to the drive motor).
3. Infrastructure Layer
- Hardware abstraction (functions or a small controller class) wraps:
- Servo control (angle → microsecond pulse → PCA9685 duty cycle).
- Motor control (forward/backward duty mapping).
- Raw sensor reads (ultrasonic, ToF, IMU).
- Configuration & logging
- Constants for thresholds and speeds are loaded from code and optional JSON files.
- Runtime logs (print statements or optional CSV export) record timestamps, state, yaw, distances, and detection results for offline analysis and tuning.
I
n calibration/debug mode, the same program can run with more verbose logging and lower speeds; in competition mode, it uses a fixed configuration and headless start button, respecting the WRO start-up rules (power switch + separate start button).

### 3.1 Code Structure

### 3.1.1 Imports

### 3.1.1.1 External Libraries

- cv2, numpy: computer vision (colour conversion, masks, contours, geometry).
- picamera2: frame capture from the Raspberry Pi camera.
- adafruit_pca9685: PWM driver for motor and steering servo.
- adafruit_mpu6050: IMU (gyro-Z readings).
- adafruit_vl53l0x and/or gpiozero.DistanceSensor: distance sensors (front, left, right).
- threading, time, collections.deque: concurrency and timing.

### 3.1.2 Global Configuration

- Camera & vision
- Camera resolution, frame rate, and rotation.
- HSV ranges for blue/orange lane lines, red/green traffic signs, and magenta parking markers.

- Cropping percentages (top/bottom/left/right) to restrict processing to relevant regions of interest.
- Motion & safety
- Speed setpoints for normal lap driving, sign-approach slowdown, obstacle approach, parking search, and parking manoeuvre.
- Distance thresholds for “safe to go”, “slow down”, and “must stop”.
- Yaw-related constants for turning and for recovering the straight heading after obstacle avoidance.

Configuration is initialised with sensible defaults and can optionally be overridden by loading a JSON file so that competition tuning does not require editing the code.

### 3.1.3 Perception Helpers

- Lane detection
- preprocess_lane(frame): crop, blur, convert to HSV, and threshold for blue/orange.
- find_lane_center(mask): compute the lane centre (cx) within a horizontal ROI; return an offset from the image centre.
- Traffic sign detection
- detect_signs(frame): threshold for red and green in a near-front ROI, extract contours, filter by area/aspect ratio, and classify each detection as “GREEN_LEFT” or “RED_RIGHT”.
- The closest valid detection is converted into a discrete lane side command that remains active until the next sign.
- Parking detection
- detect_parking(frame): search for magenta regions near the right-hand border (or according to starting direction), and output a Boolean “parking_slot_visible” plus approximate geometry.

### 3.2 Control & FSM

- A small enum or set of constants describes the FSM states (e.g. IDLE, LAP_DRIVE,
SIGN_HANDLE, | OBSTACLE_STOP, | PARK_SEARCH, | PARK_ALIGN, | PARK_EXECUTE,
FINISHED).
- The main loop:
1. Grabs a new frame from the camera.
2. Reads distance sensors and IMU (gyro-Z).
3. Updates yaw by integrating gyro-Z.

4. Runs perception helpers to update lane centre, active lane side, sign presence, and parking visibility.
5. Calls the FSM step function, which decides:
- Current speed setpoint.
- Steering angle.
- State transitions (e.g., after three laps, when a sign is recognised, or when the parking lot comes into view).

All actuation goes through a small abstraction layer so that the FSM code remains readable and declarative (“set speed to PARK_SLOW”, “steer to lane_center_angle”) rather than dealing directly with PWM counts.

### 4 Decision‑Making Architecture

The decision-making logic separates perception, state-based intent, and low-level actuation. Each step uses explicit thresholds, timeouts, and hysteresis to avoid unstable behaviour.

### 4.1 Perception Pipeline

1. Lane model
- The bottom part of the image (road near the front of the robot) is cropped and thresholded for blue/orange to obtain a binary mask of lane markings.
- The mask is collapsed horizontally to estimate a lane centre and its offset relative to the image centre.
- This offset is converted into a desired steering angle, with a dead-band around zero to avoid constant micro-corrections.
2. Traffic sign model
- A forward ROI is scanned for red and green blobs with the expected pillar size and aspect ratio.
- If a green pillar is detected, the robot sets a mode flag lane_side = LEFT. If a red pillar is detected, it sets lane_side = RIGHT.
- Once set, lane_side remains active for the current section until another valid sign is detected, mirroring the rule that signs indicate which side to keep rather than a one-frame command.
3. Parking lot model
- When the “laps completed” condition is satisfied, the perception pipeline starts looking for magenta rectangles corresponding to parking lot limitations.

- As the robot approaches, the relative size and position of the magenta blobs are used to align the vehicle beside the slot and to trigger the parking manoeuvre.
4. Range & heading
- Front distance: used to slow down/stop before walls, traffic signs, or unexpected obstacles.
- Left/right distances: used for additional wall-distance safety and as a fallback estimate when lane markings are momentarily lost.
- Yaw (integrated gyro-Z): used to stabilise turns, recover original heading after obstacle avoidance, and keep the vehicle aligned during straight segments.

### 4.2 Behavioural Logic

- Lane following under sign constraints
- The controller computes a desired lateral offset based on lane_side:
- If lane_side = LEFT, target the left half of the lane.
- If lane_side = RIGHT, target the right half of the lane.
- The lane-centre offset is combined with this target to produce a steering command.
- If lane markings are temporarily lost, the controller falls back to yaw (keep last heading) and side distances (keep a safe margin to the visible wall).
- Obstacle handling
- If the front distance falls below a safety threshold, the robot enters an obstacle/stop behaviour:
- Speed is ramped down to zero.
- The robot waits for a short period and checks again.
- If the path becomes clear (e.g., a false positive or transient reflection), the robot resumes lane following.
- If the obstacle remains, the FSM may choose a slow “creep” or fail-safe to avoid pushing traffic signs.
- Lap counting
- Laps are counted either by yaw-based corner counting (similar to the 1st mission) or by crossing detection of a specific lane pattern near the start section.
- Once three laps are completed, all sign-based lane decisions are ignored, and the FSM transitions to the parking phase, while still maintaining safety distance rules.
- Parking

- In the parking phase, decisions are dominated by parking-related detections:
- The robot searches for magenta parking markers.
- When detected, it aligns longitudinally and laterally using a combination of lane centre, yaw, and distance sensors.
- The parallel parking manoeuvre is executed as a sequence of controlled reverse/forward segments with predefined steering angles, finalising when the car is inside and aligned.

All decisions rely on clear numeric thresholds defined in the configuration (e.g. minimum sign area, distance to start slowing, yaw error tolerance). This makes the behaviour reproducible and tunable between rounds.

### 5 Finite State Machine (FSM)

The Obstacle Challenge controller uses a finite state machine to structure behavior into clear phases. Below is a conceptual FSM; the exact constant names in the code can follow this mapping.

### 5.1 States

State | Enter | Actions | Exit
IDLE | Program started; waiting for Start button | Motors off; centre steering; zero lap counter and yaw bias | Start button pressed → LAP_DRIVE
LAP_DRIVE | Start pressed; laps < 3 | Lane following under current lane_side; obey sign updates; normal speed | Front too close → OBSTACLE_STOP; laps = 3 → PARK_SEARCH
OBSTACLE_STOP | Front distance < STOP_DIST (any time) | Ramp speed to 0; keep heading; wait OBSTACLE_WAIT_TIME and re-check | Path clear → back to previous (usually LAP_DRIVE); hard timeout → FINISHED (fail-safe)
PARK_SEARCH | Laps completed (≥3) | Ignore new sign instructions; drive slowly; search for parking markers | Parking lot detected → PARK_ALIGN
PARK_ALIGN | Parking markers visible | Align alongside slot using lane, magenta markers, yaw, and side distances | Alignment constraints met → PARK_EXECUTE

### 5.2 Sate actions

- IDLE
- On entry: all counters cleared, yaw integration reset, and any sign/lane flags reset.

- Guard: only the physical Start button or an explicit software command can leave this state.
- CRUISE
- Normal driving mode for the three laps.
- Uses lane detection plus lane_side (from sign detection) to compute steering.
- Speeds and accelerations are tuned for lap time while staying safely below distance and yaw limits.
- Transition to OBSTACLE_STOP if d_front < STOP_THRESHOLD.
- Lap detection increments lap_count; when lap_count >= 3, the state transitions to PARK_SEARCH.
- OBSTACLE_AVOID
- Purpose: honour the rule that traffic signs must not be pushed or moved.
- Immediate cut of motor PWM and brake by coasting to stop.
- Waits for OBSTACLE_WAIT_TIME; if the obstacle is still too close, the robot either remains stopped or executes a very cautious low-speed creep, but never applies enough force to move pillars.
- PARK_SEARCH
- Lateral behaviour is simplified (e.g. keep right side of lane, independent of previous sign rules).
- The vision pipeline prioritises magenta detection; other detections are ignored except for safety.
- Speed is reduced to improve detection reliability and parking precision.
- PARK_ALIGN
- Robot positions itself parallel to the parking slot, at a known offset:
- Yaw is corrected so car faces along the lane.
- Distance from the parking boundary is adjusted using side sensors.
- When alignment error (in yaw and lateral distance) is below configurable thresholds, transition to PARK_EXECUTE.
- PARK_EXECUTE
- Parallel parking sequence:
- Reverse with steering into the slot until a distance or time threshold.

- Counter-steer forward slightly to centre the vehicle.
- During the manoeuvre, yaw and distances are monitored to avoid collisions with parking boundaries.
- FINISHED
- Terminal state for a successful run (three laps + parking).
- Motors remain off; the robot awaits manual retrieval or a reset command.

This FSM keeps the mission logic explicit and easy to explain to judges: every behaviour change is tied to a specific sensor condition or mission milestone (lap count, sign detection, parking detection).

### 6 Diagrams

### 6.1 Pinout / Wiring (Conceptual)

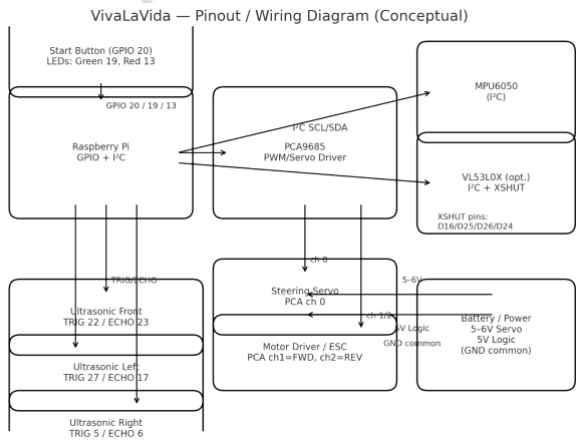
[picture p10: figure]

### 7 Appendix A - Variables

Notes
- Units:
- Distances in centimetres (cm).
- Time in seconds (s).
- Angles in degrees (°).
- Speeds as 0–100 % motor PWM.
- Many variables are shared with the 1st mission (speeds, basic safety thresholds, yaw filtering). The 2nd mission adds a new group of vision-related and parking-related variables.
Below is a non-exhaustive list of the most important variables grouped by function.
- Initialization & Mode
- USE_CAMERA
Enables/disables the camera and vision pipeline (for testing with only distance sensors). Values: 0 = disabled, 1 = enabled.
- START_DIRECTION
Encodes whether the run is clockwise or counter-clockwise, affecting lane-side interpretation and parking search direction.
Values: "CW", "CCW" (or 0/1).
- USE_TOF_FRONT / USE_TOF_SIDES
Select ToF or ultrasonic sensors for front and side measurements. Values: 0 = ultrasonic, 1 = ToF.
- Lane & Sign Detection
- HSV_BLUE_LOW/HIGH, HSV_ORANGE_LOW/HIGH
HSV ranges used to detect lane markings on the mat (blue and orange lines).
Notes: Tuned once under competition lighting, kept stable thereafter.
- HSV_RED_LOW/HIGH, HSV_GREEN_LOW/HIGH
HSV ranges used to detect red and green traffic signs. Based on the official RGB values of the pillars; slightly expanded to allow for lighting changes.
- SIGN_MIN_AREA
Minimum contour area in pixels for a candidate to be considered a valid traffic sign (filters out noise).
- SIGN_MAX_ASPECT
Maximum allowed width/height ratio to still be considered a “pillar”. Very wide blobs are rejected.
- SIGN_PERSIST_FRAMES
Number of consecutive frames a detection must appear before lane_side is updated. Helps avoid flicker.
- LANE_ROI_TOP, LANE_ROI_BOTTOM (percent)
Vertical cropping percentages (0–1) defining the lane-detection band near the bottom of the image.
- LANE_DEAD_BAND
Range of lane centre offsets (in pixels or normalised units) considered “good enough” to drive straight.
- LANE_KP, LANE_MAX_CORR
Proportional gain and maximum allowed steering correction from lane offset to servo angle.
- Parking Detection & Manoeuvre
- HSV_MAGENTA_LOW/HIGH
HSV ranges used to detect the magenta parking lot limitations.

- PARK_MIN_AREA
Minimum contour area for a magenta region to be treated as a parking marker.
- PARK_EDGE_MARGIN
How far from the image borders magenta blobs are expected when the robot is correctly aligned with the slot.
- PARK_ALIGN_LAT_TOL
Allowed lateral distance error (cm) between the car and the parking boundary before the manoeuvre starts.
- PARK_ALIGN_YAW_TOL
Allowed yaw error (°) before starting the parallel parking sequence.
- PARK_BACK_DIST, PARK_FORWARD_DIST
Target reverse and forward travel distances (or equivalent times) during the parking manoeuvre.
- PARK_SPEED
Speed used during parking; typically much lower than lap speed for precision.
- Speeds & Safety (shared with 1st mission, re-used here)
- SPEED_LAP / SPEED_SIGN_APPROACH / SPEED_PARK_SEARCH / SPEED_PARK_EXECUTE
Main speed setpoints for each phase of the mission (see Section 6).
- STOP_THRESHOLD
Front distance (cm) below which the robot must stop immediately to avoid collisions or moving traffic signs.
- SLOWDOWN_DISTANCE
Distance at which the robot starts reducing speed near obstacles or signs.
- SIDE_SAFE_DISTANCE
Minimum acceptable distance to side walls or pillars; used as an extra guard when lane information is noisy.
- Yaw & Filtering
- YAW_FILTER_ALPHA
Exponential moving average factor applied to gyro-Z before integration (0–1; higher = less smoothing).
- YAW_STRAIGHT_TOL
Allowed yaw deviation from the target “straight” heading before corrections are applied.
- YAW_PARK_ALIGN_TOL
Stricter yaw tolerance used in the parking alignment phase.
- N_READINGS
Window size for median filtering of distance sensors.
- FILTER_ALPHA_DIST, FILTER_JUMP_DIST
EMA smoothing factor and maximum jump for distance sensors; large jumps are considered spikes and ignored.
- Timing & Mission Management
- OBSTACLE_WAIT_TIME
How long to wait in OBSTACLE_STOP before re-checking if the path is clear.
- FRAME_INTERVAL
Desired time between camera processing frames; can be increased to reduce CPU load.
- MAX_LAPS
Number of laps to drive before switching to parking logic (3 for the official Obstacle Challenge).
- TIMEOUT_PARK_SEARCH
Maximum time allowed in PARK_SEARCH before failing safely in FINISHED if the slot is never found.

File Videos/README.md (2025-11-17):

# Below you will find videos throughout the preparation phase!

# First mission - Open challenge

## [Final attempt (click here)](https://youtu.be/qEY1UPajjtA)

# Second mission - Obstacle challenge

## [Final attempt (click here)](https://youtu.be/k25_KGx6__c)

### First mission trials
 - [1st trial](https://youtube.com/shorts/GeQqc4MKFQo?feature=share)
 - [2nd trial](https://youtu.be/qCU5bkvZXJk)

### Middle lane canny (first verion)
>  https://www.youtube.com/watch?v=V8HWPlmeNno

### 3D printing process
>  https://youtube.com/shorts/2Z2sEL-jba4?feature=share

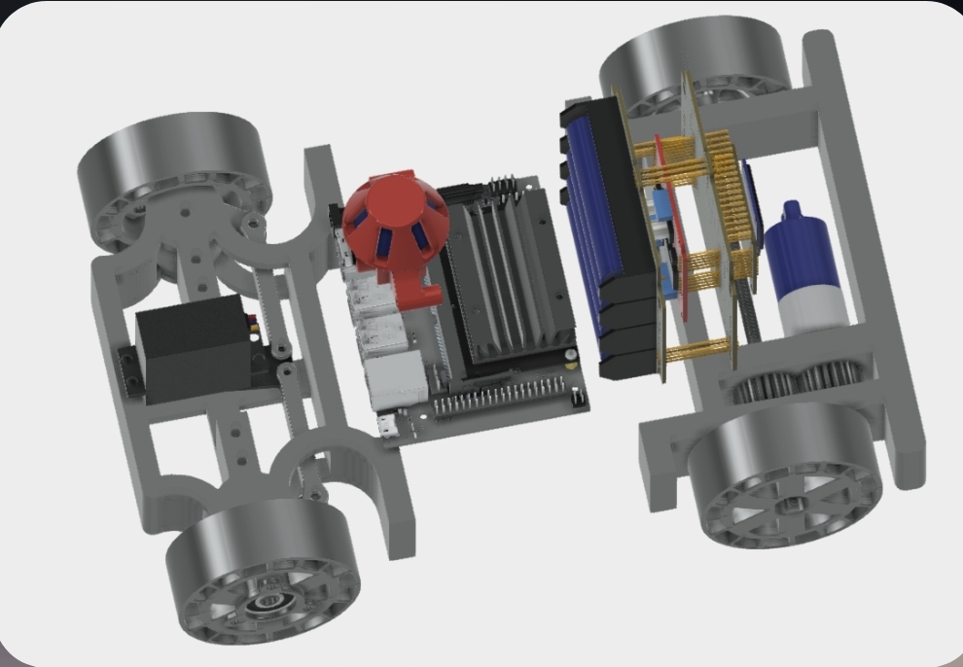
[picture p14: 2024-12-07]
Robot Photos/Robot prototype/ROBOT_PROTOTYPE_TOPVIEW.jpg

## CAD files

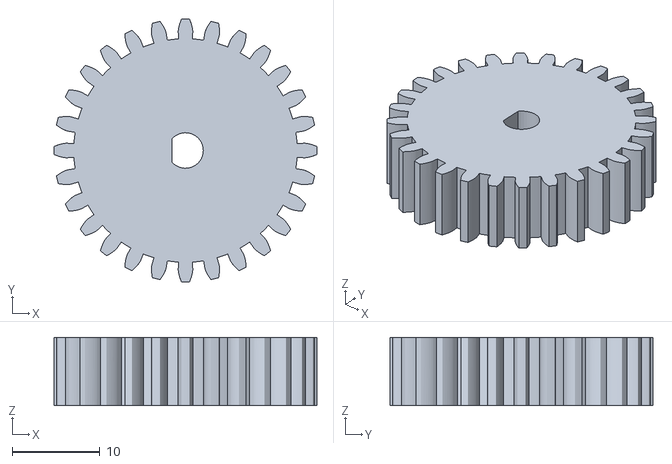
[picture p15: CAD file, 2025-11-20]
3d designs/3d schematics/VLV-motorgear-final.stl
30.0 x 30.0 x 7.80

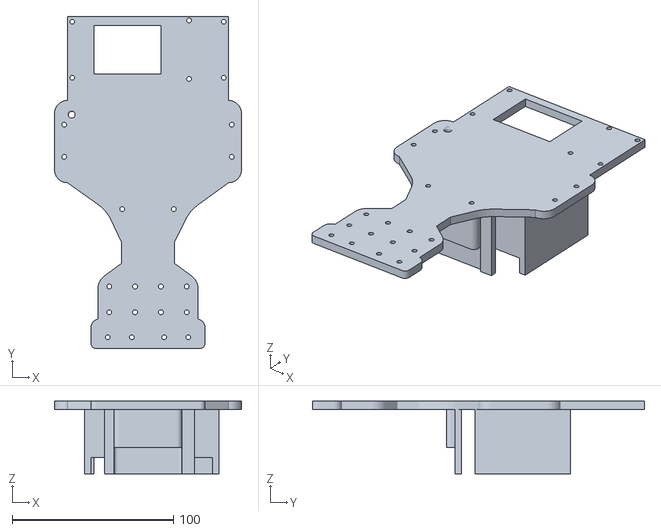
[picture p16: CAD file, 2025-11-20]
3d designs/3d schematics/VLV-chassis-final.stl
116.0 x 206.0 x 45.0

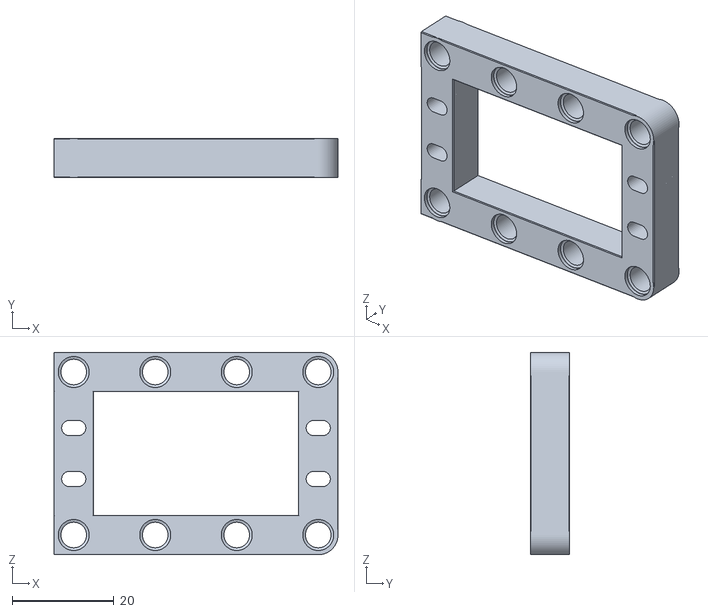
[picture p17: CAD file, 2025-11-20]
3d designs/3d schematics/VLV-servoholder-final.stl
55.8 x 7.75 x 39.8

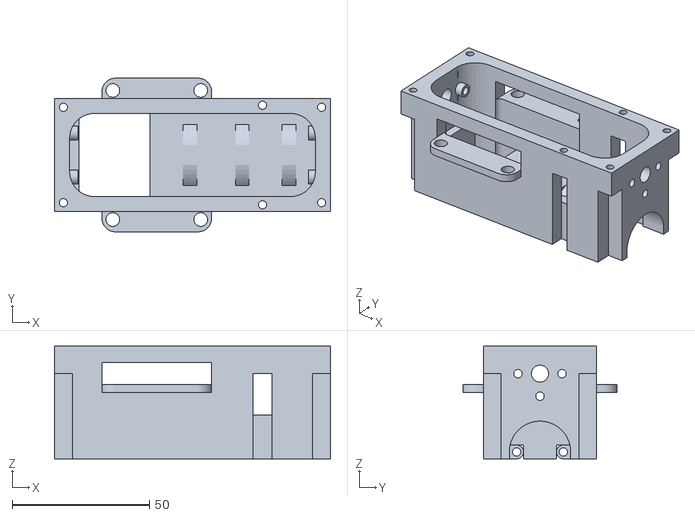
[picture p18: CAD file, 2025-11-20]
3d designs/3d schematics/VLV-motorbase-final.stl
100.5 x 56.0 x 41.0

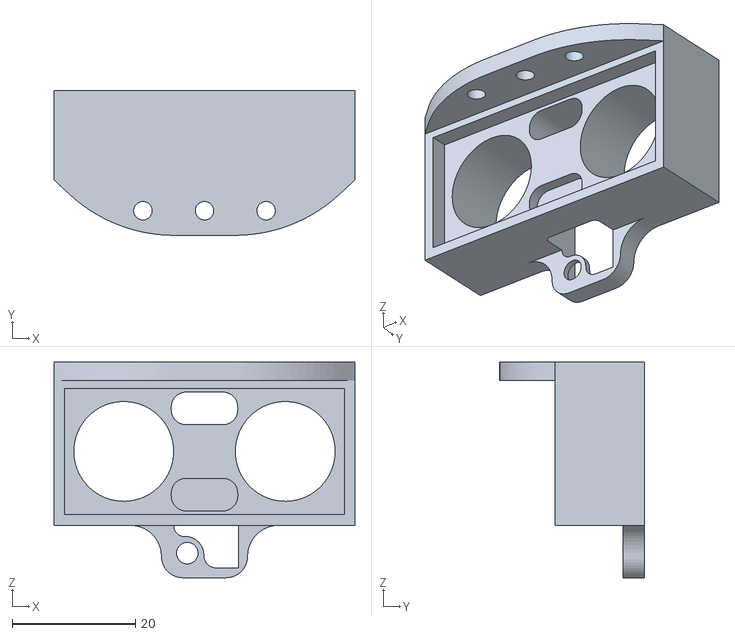
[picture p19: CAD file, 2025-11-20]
3d designs/3d schematics/VLV-disensorbase-final.stl
48.9 x 23.5 x 35.0

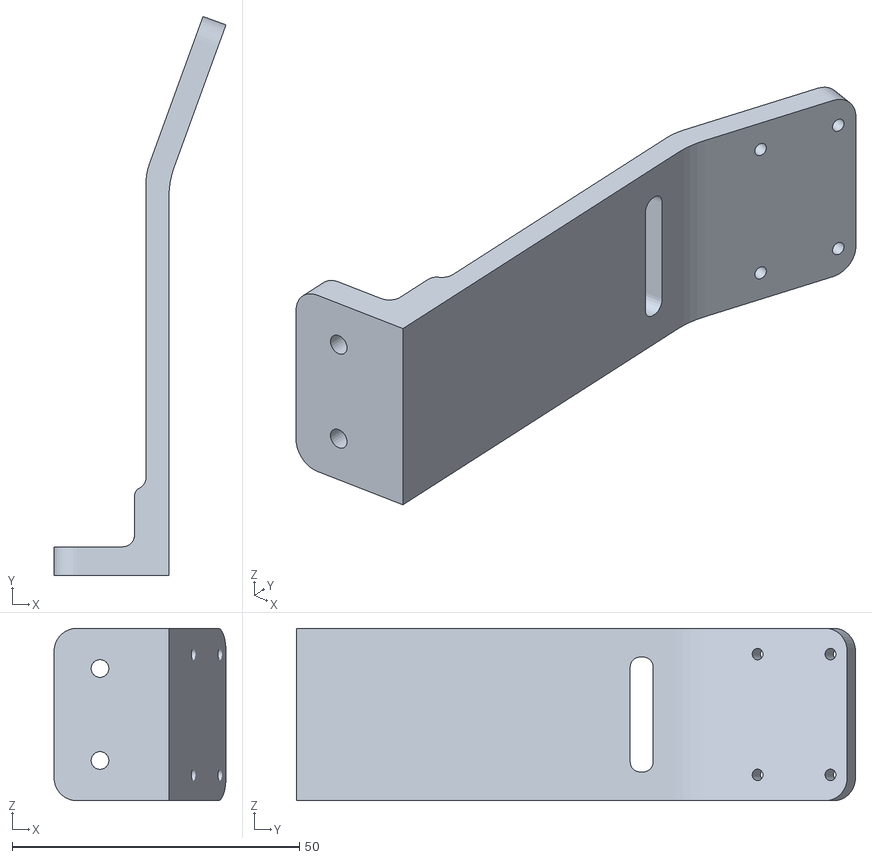
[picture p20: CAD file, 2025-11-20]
3d designs/3d schematics/VLV-camerabase-final.stl
29.9 x 97.3 x 30.0

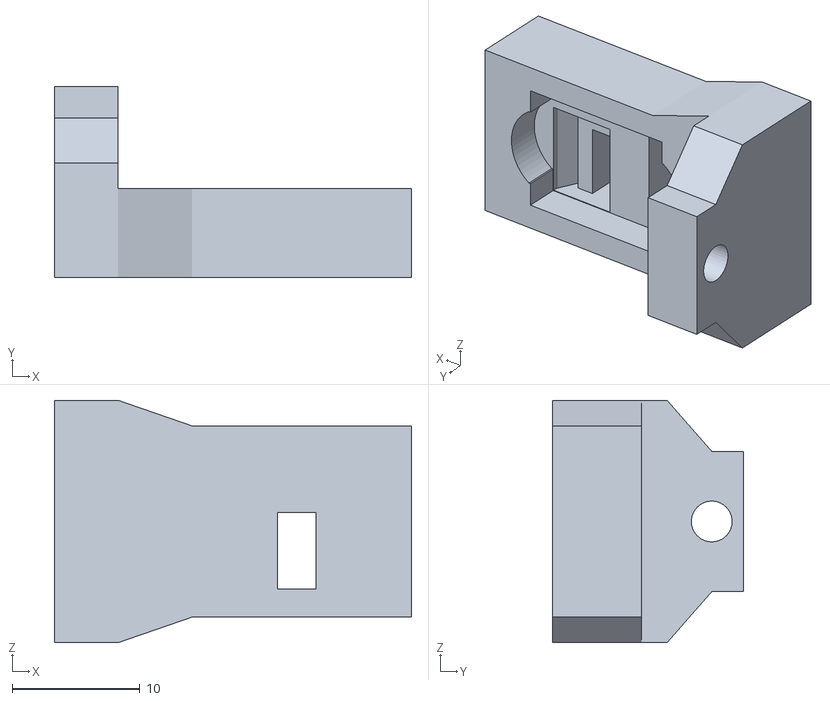
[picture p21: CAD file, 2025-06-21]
3d designs/3d schematics/VLV-Tof-final.stl
28.0 x 15.0 x 19.0

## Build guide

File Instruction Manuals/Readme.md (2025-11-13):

# Here you can find manuals to construct a replica of our robot 🤖
## All instruction manuals have been created entirely by us and are free to use
> [!TIP]
> Ensure that you have prepared the parts needed for each section before starting

### Here's an image of all the parts that make up our robot when dissasembled:
Full layout 2

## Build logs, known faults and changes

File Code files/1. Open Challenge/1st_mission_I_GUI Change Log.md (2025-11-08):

Autonomous drive 1st Mission WRO 2025
- VivaLaVida - 

v4.1 - remove camera, add logging
v4.2 - improved turn logic and timeout slider
v4.3 - graph and turn improvements
v4.5 - rewrite
v4.5 - new turn logic with PID clear after turn
v4.6 - new wall following rules
v4.7 - new GUI, rewrite
v4.8 - added gyroscope
v4.9 - added sliders, max lap, save/load slide values, csv export with data
v4.92 - check servo correction during cruise
v4.93 - add lap reset button (stop loop), slider name correction
v4.94 - Sensor readings filtering improvements, read in sequence. Lock turn side. Improve driving between walls with new rules.
v4.95 - Code cleaning, turn based on gyroscope
v4.96 - add/remove corrections
v4.98 - turn initiation stop logic (merge from v4.7-4.8 plus extra conditions), added tof
v4.98FSM - finite state machine (FSM)
v4.99 - option to run w/o GIO

v5.0 - Gold version
v5.1 - minor fixes
v5.2 - threaded, low-latency sensor reading, Exponential Moving Average (EMA) layer, turn initiation logic
v5.3:
     - fix stop loop to stop the motor (change at RobotState.IDLE), 
     - added timing and continuous reading in tof initialization and also changed tof settings on closing, 
     - added linear accelaration in RobotState.IDLE during start, 
     - def sensor_reader reduced sleep (0.005 from 0.01)
v5.4:
     - gpiozero, 
     - added SENSOR_DELAY variable, 
     - speed factor per state
     - last_turn_time set to a high value to enable initial turn
     - Removed logic to end turn based on front/side distance
v5.5:
     - add numners to plots
     - changes def turn_decision
v5.51:
     - fixed start readings button 
v5.52:
     - code cleaning
v5.53:
     - factor to change variables if in between narrow walls
v5.6:
     - code cleaning
     - bugs to fix: turn init speed probably not working, check speed sliders if ok, check BASE speeds if needed
v5.61:
     - efficiency improvements (Events + responsive waits, High-precision timing with monotonic_ns
v5.62:
     - stop due to obstacle (wait for clear front to continue)
     - code cleaning
v5.63:
     - Turn init state/speed fix
     - Variable to adjust servo speed
v5.64:
     - load variables from json file
v5.7:
     - code cleaning
v5.8:
     - performance improvements TBD
     - turning improvements (yaw calculation)
v5.9:
     - fix tof readings
v5.91:
     - minor improvements
v5.92:
     - change safe straight control logic
     - code cleaning
v5.93:
     - add front side ToF sensors, turning logic
v5.94:
     - remove RiGPIO
v5.95:
     - corrections on exit
     - move GUI imports to launch GUI section (remove from headless)
v5.96:
     - corrections on safe straight control
     - code cleaning

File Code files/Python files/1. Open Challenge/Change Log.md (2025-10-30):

-----------------------------------------------------------------------------------------------------------------------
Autonomous drive 1st Mission WRO 2025
- VivaLaVida - 

v5.0 - Gold version
v5.1 - minor fixes
v5.2 - threaded, low-latency sensor reading, Exponential Moving Average (EMA) layer, turn initiation logic
v5.3:
     - fix stop loop to stop the motor (change at RobotState.IDLE), 
     - added timing and continuous reading in tof initialization and also changed tof settings on closing, 
     - added linear accelaration in RobotState.IDLE during start, 
     - def sensor_reader reduced sleep (0.005 from 0.01)
v5.4:
     - gpiozero, 
     - added SENSOR_DELAY variable, 
     - speed factor per state
     - last_turn_time set to a high value to enable initial turn
     - Removed logic to end turn based on front/side distance
v5.5:
     - add numners to plots
     - changes def turn_decision
v5.51:
     - fixed start readings button 
v5.52:
     - code cleaning
v5.53:
     - factor to change variables if in between narrow walls
v5.6:
     - code cleaning
     - bugs to fix: turn init speed probably not working, check speed sliders if ok, check BASE speeds if needed
v5.61:
     - efficiency improvements (Events + responsive waits, High-precision timing with monotonic_ns
v5.62:
     - stop due to obstacle (wait for clear front to continue)
     - code cleaning
v5.63:
     - Turn init state/speed fix
     - Variable to adjust servo speed
v5.64:
     - load variables from json file
v5.7:
     - code cleaning

Notes: 
- Correction active is only available in cruise and not in turn init
TO DO - Change variables (speed etc) if wall is narrow
TO DO - check time.sleep(LOOP_DELAY) if needed in all instances
TO DO - test end turn only with gyro and not distances
to do: add buttons & leds & buzzer
to do: reduce speed if sensors are none or before turning, logic for movements after stop due to obstacle

TIPS:
-adjust max distance for Ultrasonic sensor readings (eg max 1m for side)
-use lower delay time
----------------------------------------------------------------------------------------------------------------------

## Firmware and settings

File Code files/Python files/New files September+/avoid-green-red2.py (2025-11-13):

# ======= BOX AVOID + IMU (yours) + SHAPE-ONLY LINE TURN (ALWAYS LEFT, FIXED + 5s MIN TURN INTERVAL + STRONGER NO-BOX IMU) =======

import cv2
import numpy as np
from picamera2 import Picamera2
import time
from pca9685_control import set_servo_angle, set_motor_speed
import smbus2
import threading

# ToF deps
import board
import busio
import digitalio
import adafruit_vl53l0x
from gpiozero import Button

# ==== CONSTANTS ====
MOTOR_FWD = 1
MOTOR_REV = 2
SERVO_CHANNEL = 0
CENTER_ANGLE = 90
LEFT_FAR = 110
LEFT_NEAR = 130
RIGHT_FAR = 70
RIGHT_NEAR = 50
new_servo_angle = 90

STEP = 6
FAST_SERVO_STEP = 9
SERVO_UPDATE_DELAY = 0.00

MIN_AREA = 2000
MAX_AREA = 20000
COLOR_HOLD_FRAMES = 5

# ToF thresholds
SIDE_COLLIDE_CM = 30.0
TURN_SIDE_REQ_CM = 40.0
TURN_FRONT_REQ_CM = 60.0
TOF_TURN_FRONT_MAX_CM = 80.0
TOF_TURN_LEFT_MIN_CM = 80.0

# New "stuck" escape thresholds
FRONT_STUCK_CM = 7.0       # if front < 7cm and no boxes/line -> emergency reverse
BACK_CLEAR_CM  = 10.0      # reverse until back >= 10cm
EMERGENCY_BACK_SPEED = 18
EMERGENCY_TURN_DEG   = 60.0

# ==== BLUE-BOX BACKWARD LOGIC ====
blue_backward_start = None
in_blue_backward = False
BLUE_BACK_DURATION = 1.5
BLUE_BACK_SPEED = 13

# ==== AVOIDANCE LOGIC ====
AVOID_BACK_DURATION = 1.0
AVOID_SPEED = 16

# ==== NORMAL LINE FOLLOWING SPEED ====
NORMAL_SPEED  = 17

# ==== LINE TURN (shape-only, diagonal band) ====
TURN_LEFT_SERVO = 60
TURN_IMU_TARGET_DEG = 75.0
TURN_COOLDOWN_S = 0.7
TURN_MIN_INTERVAL_S = 5.0
CANNY_LO, CANNY_HI = 60, 160
BLUR_KSIZE = 5
HOUGH_THRESHOLD = 60
HOUGH_MIN_LENGTH = 120
HOUGH_MAX_GAP = 20
LINE_DETECT_CONSEC_FRAMES = 2
LINE_ORIENT_MIN_DEG = 25
LINE_ORIENT_MAX_DEG = 65
LINE_MASK_THICKNESS = 8

# ==== COLOR HSV RANGES (calibrated) ====
RED1_LO   = np.array([0,   140, 120], dtype=np.uint8)
RED1_HI   = np.array([5,   255, 190], dtype=np.uint8)
RED2_LO   = np.array([0,   140, 120], dtype=np.uint8)
RED2_HI   = np.array([5,   255, 190], dtype=np.uint8)

GREEN_LO  = np.array([65,   90,  90], dtype=np.uint8)
GREEN_HI  = np.array([80,  255, 150], dtype=np.uint8)

ORANGE_LO = np.array([6,  140, 180], dtype=np.uint8)
ORANGE_HI = np.array([14, 200, 210], dtype=np.uint8)

BLUE_LO   = np.array([112, 140, 120], dtype=np.uint8)
BLUE_HI   = np.array([118, 230, 160], dtype=np.uint8)


# dynamic turn/trigger tuning
BLUE_Y_TRIGGER_FRAC = 0.78
BLUE_MIN_LEN_PX = 70
TURN_YAW_MIN_DEG = 55.0
TURN_YAW_MAX_DEG = 95.0

SETTLE_DURATION = 0.0
settle_until_ts = 0.0

# --- post-reverse follow window ---
POST_BACK_FOLLOW_S = 0.7  # seconds to keep steering toward the box after the reverse

# ==== IMU SETUP ====
MPU6050_ADDR = 0x68
PWR_MGMT_1 = 0x6B
GYRO_ZOUT_H = 0x47
bus = smbus2.SMBus(1)

def mpu6050_init():
    bus.write_byte_data(MPU6050_ADDR, PWR_MGMT_1, 0)

def read_raw_data(addr):
    high = bus.read_byte_data(MPU6050_ADDR, addr)
    low = bus.read_byte_data(MPU6050_ADDR, addr+1)
    value = (high << 8) | low
    if value > 32767:
        value -= 65536
    return value

def get_gyro_z_bias(samples=200):
    total = 0.0
    for _ in range(samples):
        raw = read_raw_data(GYRO_ZOUT_H)
        total += raw / 131.0
        time.sleep(0.005)
    return total / samples

mpu6050_init()
print("Measuring gyro bias, keep sensor still...")
gyro_z_bias = get_gyro_z_bias()
print(f"Gyro Z bias: {gyro_z_bias:.3f} deg/s")

# adaptive drift control
DRIFT_GZ_THRESH = 0.8
BIAS_ALPHA = 0.002
STRAIGHT_SERVO_WINDOW = 8
DRIFT_DECAY_RATE = 0.20

# --- stability gates ---
YAW_CLAMP_DEG = 120.0
SIDE_CLEAR_CM = 40.0
SIDE_BALANCE_CM = 8.0
CALM_GZ_THRESH = 0.35
HARD_DECAY_RATE = 2.0
SOFT_DECAY_RATE = 0.6
CENTER_LOCK_WINDOW = 4

# --- post-turn avoidance grace (color-specific) ---
POST_TURN_GRACE_GREEN_S = 5.00
POST_TURN_GRACE_RED_S   = 0.15

# ==== YAW TRACKING ====
yaw = 0.0
yaw_lock = threading.Lock()
last_time = time.time()

def reset_yaw_listener():
    global yaw
    while True:
        input("Press ENTER to reset yaw to 0°")
        with yaw_lock:
            yaw = 0.0
            print("Yaw reset to 0°")

threading.Thread(target=reset_yaw_listener, daemon=True).start()

# ---- IMU keep-straight (proportional) ----
YAW_DEADBAND_DEG_BASE = 3.0
YAW_KP_BASE = 1.0
SERVO_CORR_LIMIT_BASE = 22
YAW_DEADBAND_DEG_STRONG = 2.0
YAW_KP_STRONG = 1.04
SERVO_CORR_LIMIT_STRONG = 26

def imu_center_servo(current_yaw_deg: float, deadband: float, kp: float, limit: float) -> int:
    if abs(current_yaw_deg) <= deadband:
        return CENTER_ANGLE
    corr = kp * current_yaw_deg
    corr = max(-limit, min(limit, corr))
    return int(CENTER_ANGLE + corr)

# ==== SERVO SETUP ====
set_servo_angle(SERVO_CHANNEL, CENTER_ANGLE)
current_servo_angle = CENTER_ANGLE

# --- servo stabilizer ---
SERVO_SMOOTH_ALPHA = 0.35
SERVO_MIN_DELTA_DEG = 2.0

# ==== CAMERA SETUP ====
picam2 = Picamera2()
picam2.configure(picam2.create_preview_configuration(main={"size": (640, 480)}))
picam2.start()

# ==== ToF SETUP ====
i2c = busio.I2C(board.SCL, board.SDA)
xshut_pins = {
    "left": board.D16,
    "right": board.D25,
    "front": board.D26,
    "back": board.D24
}
addresses = {
    "left": 0x30,
    "right": 0x31,
    "front": 0x32,
    "back": 0x33
}

xshuts = {}
for name, pin in xshut_pins.items():
    x = digitalio.DigitalInOut(pin)
    x.direction = digitalio.Direction.OUTPUT
    x.value = False
    xshuts[name] = x
time.sleep(0.1)

sensors = {}
for name in ["left", "right", "front", "back"]:
    xshuts[name].value = True
    time.sleep(0.05)
    s = adafruit_vl53l0x.VL53L0X(i2c)
    s.set_address(addresses[name])
    s.start_continuous()
    sensors[name] = s
    print(f"[TOF] {name.upper()} active at {hex(addresses[name])}")

def tof_cm(sensor):
    try:
        val = sensor.range / 10.0
        if val <= 0 or val > 150:
            return 999
        return val
    except:
        return 999

# ==== HELPERS ====
def get_largest_contour(mask, min_area=500):
    contours, _ = cv2.findContours(mask, cv2.RETR_EXTERNAL, cv2.CHAIN_APPROX_SIMPLE)
    if not contours:
        return None
    largest_contour = max(contours, key=cv2.contourArea)
    if cv2.contourArea(largest_contour) < min_area:
        return None
    x, y, w, h = cv2.boundingRect(largest_contour)
    return largest_contour, (x, y), (x + w, y + h), w*h

def thin_shape_reject(candidate, min_extent=0.30, ar_lo=0.35, ar_hi=3.0):
    if not candidate:
        return None
    cnt, tl, br, area = candidate
    x1, y1 = tl; x2, y2 = br
    w, h = x2 - x1, y2 - y1
    if w <= 0 or h <= 0:
        return None
    ar = w / float(h)
    if not (ar_lo <= ar <= ar_hi):
        return None
    extent = cv2.contourArea(cnt) / float(w * h)
    if extent < min_extent:
        return None
    return candidate

def compute_servo_angle(color, area):
    norm_area = max(MIN_AREA, min(MAX_AREA, area))
    closeness = (norm_area - MIN_AREA) / (MAX_AREA - MIN_AREA)
    if color == "Red":
        return int(LEFT_FAR + closeness * (LEFT_NEAR - LEFT_FAR))
    else:
        return int(RIGHT_FAR - closeness * (RIGHT_FAR - RIGHT_NEAR))

def boxes_intersect(box1, box2):
    x1_min, y1_min, x1_max, y1_max = box1
    x2_min, y2_min, x2_max, y2_max = box2
    return not (x1_max < x2_min or x1_min > x2_max or y1_max < y2_min or y1_min > y2_max)

def valid_orientation(x1,y1,x2,y2):
    dx = x2-x1; dy = y2-y1
    ang = abs(np.degrees(np.arctan2(dy, dx)))
    return LINE_ORIENT_MIN_DEG <= ang <= LINE_ORIENT_MAX_DEG

def max_line_len(lines):
    if lines is None:
        return 0
    m = 0
    for x1, y1, x2, y2 in lines[:, 0]:
        L = int(np.hypot(x2 - x1, y2 - y1))
        if L > m:
            m = L
    return m

def preprocess_edges(img_bgr):
    gray = cv2.cvtColor(img_bgr, cv2.COLOR_BGR2GRAY)
    clahe = cv2.createCLAHE(clipLimit=2.0, tileGridSize=(8,8))
    gray = clahe.apply(gray)
    gray = cv2.GaussianBlur(gray, (BLUR_KSIZE, BLUR_KSIZE), 0)
    edges = cv2.Canny(gray, CANNY_LO, CANNY_HI)
    return edges

def detect_line_and_mask(edges, h, w):
    band_y1, band_y2 = int(h*0.45), int(h*0.90)
    roi = edges.copy()
    roi[:band_y1,:] = 0
    roi[band_y2:,:] = 0
    lines = cv2.HoughLinesP(
        roi, rho=1, theta=np.pi/180,
        threshold=HOUGH_THRESHOLD,
        minLineLength=HOUGH_MIN_LENGTH,
        maxLineGap=HOUGH_MAX_GAP
    )
    line_mask = np.zeros((h, w), dtype=np.uint8)
    seg = None
    if lines is not None:
        for ln in lines:
            x1,y1,x2,y2 = ln[0]
            if valid_orientation(x1,y1,x2,y2):
                if seg is None:
                    seg = (x1,y1,x2,y2)
                cv2.line(line_mask, (x1,y1), (x2,y2), 255, LINE_MASK_THICKNESS)
    return (seg is not None), seg, line_mask

# ===============================
# SMART UNPARK (two-phase; faster; left-case phase 2 = 65° + extra ~60° left if direction == "left")
# ===============================
start_button = Button(20)

UNPARK_CENTER_ANGLE = CENTER_ANGLE
UNPARK_LEFT_TURN_ANGLE = 55
UNPARK_RIGHT_TURN_ANGLE = 120
UNPARK_STRAIGHT_SPEED = 17

print("\n=== SMART UNPARK START ===")
start_button.wait_for_press()
print("Button pressed! Starting sequence...")
time.sleep(1)

left_dist = tof_cm(sensors["left"])
right_dist = tof_cm(sensors["right"])
print(f"Left={left_dist:.1f}cm | Right={right_dist:.1f}cm")

if left_dist > right_dist:
    direction = "left"
    print("➡ Choosing LEFT (more open).")
else:
    direction = "right"
    print("➡ Choosing RIGHT (more open).")

# Phase 1: ~45°
with yaw_lock:
    yaw = 0.0
last_time = time.time()
first_angle = UNPARK_LEFT_TURN_ANGLE if direction == "left" else UNPARK_RIGHT_TURN_ANGLE
set_servo_angle(SERVO_CHANNEL, first_angle)
set_motor_speed(MOTOR_FWD, MOTOR_REV, UNPARK_STRAIGHT_SPEED)
while True:
    now = time.time(); dt = now - last_time; last_time = now
    Gz = (read_raw_data(GYRO_ZOUT_H)/131.0) - gyro_z_bias
    with yaw_lock:
        yaw += Gz * dt; current_yaw = yaw
    if abs(current_yaw) >= 45.0:
        break

# Phase 2: ~40°
with yaw_lock:
    yaw = 0.0
last_time = time.time()
if direction == "left":
    second_angle = UNPARK_RIGHT_TURN_ANGLE; target_abs_yaw = 40.0
else:
    second_angle = UNPARK_LEFT_TURN_ANGLE;  target_abs_yaw = 40.0
set_servo_angle(SERVO_CHANNEL, second_angle)
set_motor_speed(MOTOR_FWD, MOTOR_REV, UNPARK_STRAIGHT_SPEED)
while True:
    now = time.time(); dt = now - last_time; last_time = now
    Gz = (read_raw_data(GYRO_ZOUT_H)/131.0) - gyro_z_bias
    with yaw_lock:
        yaw += Gz * dt; current_yaw = yaw
    if abs(current_yaw) >= target_abs_yaw:
        break

# Extra only for initial "left": ~60° left
if direction == "left":
    with yaw_lock:
        yaw = 0.0
    last_time = time.time()
    set_servo_angle(SERVO_CHANNEL, UNPARK_LEFT_TURN_ANGLE)
    set_motor_speed(MOTOR_FWD, MOTOR_REV, UNPARK_STRAIGHT_SPEED)
    while True:
        now = time.time(); dt = now - last_time; last_time = now
        Gz = (read_raw_data(GYRO_ZOUT_H)/131.0) - gyro_z_bias
        with yaw_lock:
            yaw += Gz * dt; current_yaw = yaw
        if abs(current_yaw) >= 60.0:
            break

# Straighten & reset yaw
set_servo_angle(SERVO_CHANNEL, UNPARK_CENTER_ANGLE)
set_motor_speed(MOTOR_FWD, MOTOR_REV, UNPARK_STRAIGHT_SPEED)
with yaw_lock:
    yaw = 0.0
print("[DONE] Unpark sequence complete. Entering vision/avoid loop...")

# ==== STATE VARIABLES ====
last_color = None
frame_count = 0
last_update_time = time.time()
state = "normal"
state_start = time.time()

line_seen_streak = 0
last_turn_end_time = -1.0
turn_active = False
straight_lock_time = 0.0

# track if a box was seen during the current turn
turn_box_seen = False
turn_target_deg_active = None

# post-reverse follow state
back_follow_angle = None
post_back_follow_until = 0.0

# turn confirmation state
blue_gate_streak = 0
TURN_FRONT_MIN_CM = 18.0
TURN_FRONT_MAX_CM = 140.0

# first-turn gate remains
FIRST_TURN_FRONT_THRESH_CM = 70.0
first_turn_gate_active = True

# NEW: emergency stuck escape state
emergency_mode = False
emergency_phase = None  # "reverse" -> "turn"
emergency_direction = None  # "left" or "right"

lines_blue = 0
lines_orange = 0

try:
    motors_started = True
    avoidance_mode = False
    avoid_direction = None
    avoid_start_time = None

    set_servo_angle(SERVO_CHANNEL, CENTER_ANGLE)
    current_servo_angle = CENTER_ANGLE
    last_update_time = time.time()

    set_motor_speed(MOTOR_FWD, MOTOR_REV, 0)
    time.sleep(0.2)

    while True:
        now = time.time()
        dt = now - last_time
        last_time = now

        raw_gz_dps = read_raw_data(GYRO_ZOUT_H)/131.0
        Gz = raw_gz_dps - gyro_z_bias
        with yaw_lock:
            yaw += Gz * dt
            if yaw > YAW_CLAMP_DEG: yaw = YAW_CLAMP_DEG
            elif yaw < -YAW_CLAMP_DEG: yaw = -YAW_CLAMP_DEG
            current_yaw = yaw

        if (not in_blue_backward) and (not avoidance_mode) and (not turn_active) and (not emergency_mode):
            near_center = abs(current_servo_angle - CENTER_ANGLE) <= STRAIGHT_SERVO_WINDOW
            if near_center and abs(raw_gz_dps) < DRIFT_GZ_THRESH:
                gyro_z_bias = (1.0 - BIAS_ALPHA)*gyro_z_bias + BIAS_ALPHA*raw_gz_dps
                yaw *= (1.0 - min(1.0, SOFT_DECAY_RATE * dt))

        img = picam2.capture_array()
        img_bgr = cv2.cvtColor(img, cv2.COLOR_RGB2BGR)
        imgHSV = cv2.cvtColor(img, cv2.COLOR_RGB2HSV)
        h_img, w_img = img_bgr.shape[:2]
        blue_y_trig = int(h_img * BLUE_Y_TRIGGER_FRAC)

        edges = preprocess_edges(img_bgr)
        line_seen_raw, line_seg, line_mask = detect_line_and_mask(edges, h_img, w_img)
        time_since_last_turn = (time.time() - last_turn_end_time)
        out_of_cooldown = (time_since_last_turn >= TURN_COOLDOWN_S)
        out_of_min_interval = (time_since_last_turn >= TURN_MIN_INTERVAL_S)

        if not turn_active and out_of_cooldown and out_of_min_interval and not emergency_mode:
            line_seen_streak = line_seen_streak + 1 if line_seen_raw else 0
            line_seen = line_seen_streak >= LINE_DETECT_CONSEC_FRAMES
        else:
            line_seen_streak = 0
            line_seen = False

        ORANGE_H_LO, ORANGE_H_HI = 10, 32
        ORANGE_S_MIN, ORANGE_V_MIN = 80, 110
        mask_orange = cv2.inRange(
            imgHSV,
            np.array([ORANGE_H_LO, ORANGE_S_MIN, ORANGE_V_MIN], dtype=np.uint8),
            np.array([ORANGE_H_HI, 255, 255], dtype=np.uint8),
        )

        # PINK (exclude from red)
        mask_pink = cv2.inRange(
            imgHSV,
            np.array([140, 60, 120], dtype=np.uint8),
            np.array([170, 255, 255], dtype=np.uint8),
        )

        mask_red1 = cv2.inRange(imgHSV, np.array([0,100,80]),   np.array([10,255,200]))
        mask_red2 = cv2.inRange(imgHSV, np.array([0,100,80]), np.array([10,255,200]))  

        orange_lower = np.array([0, 110, 200])
        orange_upper = np.array([20, 160, 255])
        mask_orange = cv2.inRange(imgHSV, orange_lower, orange_upper)
        edges_orange = cv2.Canny(mask_orange, 50, 150)
        blue_lower = np.array([100, 110, 100])
        blue_upper = np.array([120, 220, 150])
        mask_blue = cv2.inRange(imgHSV, blue_lower, blue_upper)
        edges_blue = cv2.Canny(mask_blue, 50, 150)
        lines_orange = cv2.HoughLinesP(edges_orange, 1, np.pi / 180, threshold=50, minLineLength=50, maxLineGap=10)
        lines_blue = cv2.HoughLinesP(edges_blue, 1, np.pi / 180, threshold=50, minLineLength=50, maxLineGap=10)
        blue_len_max = max_line_len(lines_blue)
        img_lines = img.copy()

        center_x = img.shape[1] // 2

        def y_at_center(lines):
            if lines is None:
                return -1
            y_values = []
            for x1, y1, x2, y2 in lines[:, 0]:
                if x1 != x2:  # avoid vertical divide-by-zero
                    slope = (y2 - y1) / (x2 - x1)
                    y = slope * (center_x - x1) + y1
                    y_values.append(y)
                else:
                    # vertical line, take min/max depending on which side of center
                    if x1 == center_x:
                        y_values.append(max(y1, y2))
            return max(y_values) if y_values else -1

        orange_y = y_at_center(lines_orange)
        blue_y = y_at_center(lines_blue)

        # Blue mask
        blue_lower = np.array([100, 60, 80])
        blue_upper = np.array([120, 120, 170])
        mask_blue = cv2.inRange(imgHSV, blue_lower, blue_upper)
  
        mask_red  = cv2.bitwise_or(mask_red1, mask_red2)
        mask_red  = cv2.bitwise_and(mask_red, cv2.bitwise_not(mask_orange))
        mask_red  = cv2.bitwise_and(mask_red, cv2.bitwise_not(mask_pink))
        if line_mask is not None:
            mask_red = cv2.bitwise_and(mask_red, cv2.bitwise_not(line_mask))

        mask_green = cv2.inRange(imgHSV, np.array([35,60,60]), np.array([95,255,255]))
        if line_mask is not None:
            mask_green = cv2.bitwise_and(mask_green, cv2.bitwise_not(line_mask))

        k3 = np.ones((3,3), np.uint8)
        k5 = np.ones((5,5), np.uint8)
        def morph(m):
            m = cv2.morphologyEx(m, cv2.MORPH_OPEN, k3)
            m = cv2.morphologyEx(m, cv2.MORPH_CLOSE, k5)
            return m
        mask_red   = morph(mask_red)
        mask_green = morph(mask_green)

        img_contours = img_bgr.copy()
        boxes = []

        red_data = thin_shape_reject(get_largest_contour(mask_red, min_area=MIN_AREA))
        if red_data:
            _, top_left, bottom_right, area = red_data
            boxes.append(("Red", area, (*top_left, *bottom_right)))
            cv2.rectangle(img_contours, top_left, bottom_right, (0,0,255), 2)
            cv2.putText(img_contours, f"Red {int(area)}", (top_left[0], max(20, top_left[1]-6)),
                        cv2.FONT_HERSHEY_SIMPLEX, 0.5, (0,0,255), 2)

        green_data = thin_shape_reject(get_largest_contour(mask_green, min_area=MIN_AREA))
        if green_data:
            _, top_left, bottom_right, area = green_data
            boxes.append(("Green", area, (*top_left, *bottom_right)))
            cv2.rectangle(img_contours, top_left, bottom_right, (0,255,0), 2)
            cv2.putText(img_contours, f"Green {int(area)}", (top_left[0], max(20, top_left[1]-6)),
                        cv2.FONT_HERSHEY_SIMPLEX, 0.5, (0,255,0), 2)

        # mark that we saw a box during the active turn
        if turn_active and len(boxes) > 0:
            turn_box_seen = True

        center_x = img_contours.shape[1] // 2
        car_width, car_height = 300, 100
        bottom_y = img_contours.shape[0] - 10
        car_box = (center_x - car_width//2, bottom_y - car_height,
                   center_x + car_width//2, bottom_y)

        if line_seg:
            x1,y1,x2,y2 = line_seg
            cv2.line(img_contours, (x1,y1), (x2,y2), (0,255,255), 3)

        cv2.rectangle(img_contours, (car_box[0],car_box[1]), (car_box[2],car_box[3]), (255,255,255), 1)

        target_angle = CENTER_ANGLE
        motor_speed = 0

        # --------- NEW: EMERGENCY STUCK ESCAPE ----------
        f_cm = tof_cm(sensors["front"])
        l_cm = tof_cm(sensors["left"])
        r_cm = tof_cm(sensors["right"])
        b_cm = tof_cm(sensors["back"])

        if (not emergency_mode) and (not turn_active) and (not in_blue_backward) and (not avoidance_mode):
            no_boxes = (len(boxes) == 0)
            no_line  = (not line_seen)
            if no_boxes and no_line and f_cm < FRONT_STUCK_CM:
                emergency_mode = True
                emergency_phase = "reverse"
                set_servo_angle(SERVO_CHANNEL, CENTER_ANGLE)
                set_motor_speed(MOTOR_FWD, MOTOR_REV, -EMERGENCY_BACK_SPEED)

        if emergency_mode:
            if emergency_phase == "reverse":
                set_servo_angle(SERVO_CHANNEL, CENTER_ANGLE)
                set_motor_speed(MOTOR_FWD, MOTOR_REV, -EMERGENCY_BACK_SPEED)
                b_cm = tof_cm(sensors["back"])
                if b_cm >= BACK_CLEAR_CM:
                    emergency_phase = "turn"
                    emergency_direction = "left" if l_cm >= r_cm else "right"
                    with yaw_lock:
                        yaw = 0.0
                    last_time = time.time()
                    turn_servo = LEFT_NEAR if emergency_direction == "left" else RIGHT_NEAR
                    set_servo_angle(SERVO_CHANNEL, turn_servo)
                    set_motor_speed(MOTOR_FWD, MOTOR_REV, NORMAL_SPEED)

            elif emergency_phase == "turn":
                target_angle = LEFT_NEAR if emergency_direction == "left" else RIGHT_NEAR
                set_servo_angle(SERVO_CHANNEL, target_angle)
                set_motor_speed(MOTOR_FWD, MOTOR_REV, NORMAL_SPEED)
                if abs(current_yaw) >= EMERGENCY_TURN_DEG:
                    set_servo_angle(SERVO_CHANNEL, CENTER_ANGLE)
                    with yaw_lock:
                        yaw = 0.0
                    emergency_mode = False
                    emergency_phase = None
                    emergency_direction = None
                    settle_until_ts = time.time() + SETTLE_DURATION
                if cv2.waitKey(1) in [27, ord('q')]:
                    break
                continue
        # --------- END: EMERGENCY STUCK ESCAPE ----------

        # confirm corner-turn timing (stable, right moment)
        if line_seen and blue_y >= blue_y_trig and TURN_FRONT_MIN_CM <= f_cm <= TURN_FRONT_MAX_CM and blue_len_max >= BLUE_MIN_LEN_PX:
            blue_gate_streak += 1
        else:
            blue_gate_streak = 0
        ok_to_turn = (
            blue_gate_streak >= LINE_DETECT_CONSEC_FRAMES and
            out_of_cooldown and out_of_min_interval and
            (not in_blue_backward) and (not turn_active)
        )
        tof_line_turn_gate = (f_cm < TOF_TURN_FRONT_MAX_CM) and (l_cm > TOF_TURN_LEFT_MIN_CM) and line_seen
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

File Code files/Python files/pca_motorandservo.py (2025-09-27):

import time
import RPi.GPIO as GPIO
from board import SCL, SDA
import busio
from adafruit_pca9685 import PCA9685

# --- Global State ---
turns_completed = 0
direction = "left"  # default direction

# --- PCA9685 Setup ---
i2c = busio.I2C(SCL, SDA)
pca = PCA9685(i2c)
pca.frequency = 50  # Default for servos

# --- PID Constants ---
TARGET_DISTANCE = 20.0  # cm
KP = 0.8
KI = 0.0
KD = 2.3

integral = 0
last_error = 0
SERVO_CHANNEL = 0

# --- GPIO Setup ---
GPIO.setmode(GPIO.BCM)

TRIG_1, ECHO_1 = 22, 23   # Front sensor
TRIG_2, ECHO_2 = 5, 6     # Left sensor
TRIG_3, ECHO_3 = 27, 17   # Right sensor

for trig in [TRIG_1, TRIG_2, TRIG_3]:
    GPIO.setup(trig, GPIO.OUT)
    GPIO.output(trig, GPIO.LOW)

for echo in [ECHO_1, ECHO_2, ECHO_3]:
    GPIO.setup(echo, GPIO.IN)

# --- Motor Channels ---
MOTOR_FWD = 1
MOTOR_REV = 0

# --- Motor Control ---
def rotate_motor_forward():
    speed = 80
    duty_cycle = int(min(max(abs(speed), 0), 100) / 100 * 65535)
    pca.channels[MOTOR_FWD].duty_cycle = duty_cycle
    pca.channels[MOTOR_REV].duty_cycle = 0

def rotate_motor_backward():
    speed = -50
    duty_cycle = int(min(max(abs(speed), 0), 100) / 100 * 65535)
    pca.channels[MOTOR_FWD].duty_cycle = 0
    pca.channels[MOTOR_REV].duty_cycle = duty_cycle

def stop_motor():
    pca.channels[MOTOR_FWD].duty_cycle = 0
    pca.channels[MOTOR_REV].duty_cycle = 0

# --- Distance Measurement ---
def get_distance(trigger_pin, echo_pin):
    GPIO.output(trigger_pin, GPIO.HIGH)
    time.sleep(0.00001)  # 10 µs pulse
    GPIO.output(trigger_pin, GPIO.LOW)

    pulse_start, pulse_end = None, None

    # Wait for echo to start
    timeout = time.time() + 0.02
    while GPIO.input(echo_pin) == GPIO.LOW:
        pulse_start = time.time()
        if pulse_start > timeout:
            return None

    # Wait for echo to end
    timeout = time.time() + 0.02
    while GPIO.input(echo_pin) == GPIO.HIGH:
        pulse_end = time.time()
        if pulse_end > timeout:
            return None

    if pulse_start and pulse_end:
        pulse_duration = pulse_end - pulse_start
        return (pulse_duration * 34300) / 2  # cm

    return None

# --- Main Loop ---
try:
    while True:
        distance_front = get_distance(TRIG_1, ECHO_1)
        distance_left = get_distance(TRIG_2, ECHO_2)
        distance_right = get_distance(TRIG_3, ECHO_3)

        if direction == "left":
            side_sensor = distance_left
        else:
            side_sensor = distance_right

        rotate_motor_forward()

        if side_sensor is None:
            print("Sensor error, skipping cycle.")
            continue

        # Detect wall loss
        if side_sensor > 100 and distance_front and distance_front < 120:
            if direction == "left":
                print("Wall lost! Sharp LEFT turn")
                set_servo_angle(SERVO_CHANNEL, 40)
                if distance_right and distance_right > 100:
                    set_servo_angle(SERVO_CHANNEL, 110)
            else:
                print("Wall lost! Sharp RIGHT turn")
                set_servo_angle(SERVO_CHANNEL, 135)

            turns_completed += 1
            print(f"Turns completed: {turns_completed}")
            time.sleep(0.1)
            continue

        # --- PID Control ---
        error = TARGET_DISTANCE - side_sensor
        integral += error
        derivative = error - last_error
        output = KP * error + KI * integral + KD * derivative

        # Use servo min/max 50/130
        if direction == "left":
            new_angle = max(50, min(130, 90 + output))
        else:
            new_angle = max(50, min(130, 90 - output))  # mirrored for right wall

        # Direct servo control using adafruit_pca9685
        min_angle = 50
        max_angle = 130
        angle = max(min_angle, min(max_angle, new_angle))
        pulse_min = 1000  # 1ms
        pulse_max = 2000  # 2ms
        pulse = int(pulse_min + (pulse_max - pulse_min) * ((angle - min_angle) / (max_angle - min_angle)))
        pca.channels[SERVO_CHANNEL].duty_cycle = int(pulse * 65535 / 20000)  # 20ms period

        print(f"Side: {side_sensor:.1f} cm | Error: {error:.2f} | Servo: {new_angle:.1f}")
        print(f"Turns completed: {turns_completed}")

        last_error = error
        time.sleep(0.1)

except KeyboardInterrupt:
    print("Stopping safely...")
    stop_motor()
    GPIO.cleanup()

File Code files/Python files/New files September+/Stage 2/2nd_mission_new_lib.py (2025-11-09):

# ===============================================
# VIVA LaVida – FE 2025 Combined Navigation Script
# - BOX AVOIDANCE (camera red/green)
# - TURN DETECTION (blue/orange line) with "keep turning" rule
# - SMART UNPARK (ToF + button)
# - DEBUG LEDs: red (GPIO13), green (GPIO19), blue (GPIO11)
# - Area-based steering: farther box -> less turn, closest -> full turn
# Raspberry Pi 5 + Picamera2 + Adafruit PCA9685 + MPU6050 + VL53L0X
# ===============================================

import time
import threading
import cv2
import numpy as np
import smbus2
import RPi.GPIO as GPIO
from gpiozero import Button
from picamera2 import Picamera2
import board
import busio
import digitalio
import adafruit_vl53l0x
from adafruit_pca9685 import PCA9685

# ---------- CONSTANTS ----------
LOOP_DT_TARGET = 0.02
SHOW_WINDOWS = True

MOTOR_FWD = 1
MOTOR_REV = 2
SERVO_CHANNEL = 0

CENTER_ANGLE = 90
LEFT_NEAR  = 120
RIGHT_NEAR = 60
LEFT_FAR   = 110
RIGHT_FAR  = 70
SERVO_MIN  = 60
SERVO_MAX  = 120
STEP = 3
FAST_SERVO_STEP = 8
SERVO_UPDATE_DELAY = 0.015

NORMAL_SPEED = 20
AVOID_SPEED  = 20
BLUE_BACK_SPEED = 20

BLUE_BACK_DURATION = 1.0
AVOID_BACK_DURATION = 1.0

MIN_AREA = 1500
MAX_AREA = 9000
COLOR_HOLD_FRAMES = 4

AREA_RESPONSE_GAMMA = 0.9
AREA_GAIN = 1.35

CAM_SIZE = (1920, 1080)
CAR_BOX_WIDTH  = 350
CAR_BOX_HEIGHT = 100
CAR_BOX_BOTTOM_MARGIN = 10

LINE_CENTER_Y_MIN = 500
TURN_LEFT_SERVO  = 60
TURN_RIGHT_SERVO = 120
TURN_MIN_YAW_DEG = 75.0
TURN_FAILSAFE_MAX_DEG = 90.0
TURN_MOTOR_SPEED = 22

YAW_RESET_AFTER_LEFT  = 0.0
YAW_RESET_AFTER_RIGHT = 0.0

MPU6050_ADDR = 0x68
PWR_MGMT_1   = 0x6B
SMPLRT_DIV   = 0x19
CONFIG       = 0x1A
GYRO_CONFIG  = 0x1B
ACCEL_CONFIG = 0x1C
INT_ENABLE   = 0x38
GYRO_ZOUT_H  = 0x47
YAW_CLAMP_DEG = 120.0
YAW_KP            = 1.3
YAW_DEADBAND_DEG  = 2.0
SERVO_CORR_LIMIT  = 28
YAW_BOX_GAIN      = 3.8

RED1_LO = np.array([0,   140, 120], dtype=np.uint8)
RED1_HI = np.array([5,  255, 190], dtype=np.uint8)
RED2_LO = np.array([0, 140, 120], dtype=np.uint8)
RED2_HI = np.array([5, 255, 190], dtype=np.uint8)
GREEN_LO = np.array([65, 90, 90], dtype=np.uint8)
GREEN_HI = np.array([80, 255, 150], dtype=np.uint8)
ORANGE_LO = np.array([6,  140, 180], dtype=np.uint8)
ORANGE_HI = np.array([14, 200, 210], dtype=np.uint8)
BLUE_LO   = np.array([112,  140, 120], dtype=np.uint8)
BLUE_HI   = np.array([118, 230, 160], dtype=np.uint8)

LED_BLUE_PIN  = 11
LED_RED_PIN   = 13
LED_GREEN_PIN = 19

START_BUTTON_PIN = 20
UNPARK_SPEED = 25
UNPARK_LEFT_TURN_ANGLE  = 58
UNPARK_RIGHT_TURN_ANGLE = 120
UNPARK_PHASE1_TARGET_DEG = 45.0
UNPARK_PHASE2_TARGET_DEG = 40.0
UNPARK_EXTRA_LEFT_DEG    = 55.0

XSHUT_PINS = {
    "left":         board.D16,
    "right":        board.D25,
    "front":        board.D26,
    "front_right":  board.D24,
    "front_left":   board.D7,
    "back":         board.D8,
}
TOF_ADDR = {
    "left":        0x30,
    "right":       0x31,
    "front":       0x32,
    "back":        0x33,
    "front_right": 0x34,
    "front_left":  0x35,
}
TOF_RANGE_BAD = 999.0
TOF_VALID_MAX = 150.0

# 5s no-repeat turn cooldown (no time.sleep in loop)
TURN_COOLDOWN_SEC = 5.0

# Pre-emptive hard steer before reverse
PREEMPT_AREA = int(MAX_AREA * 0.55)
DANGER_MARGIN = 60

# Adafruit PCA9685 pulse mapping
SERVO_PULSE_MIN = 1000
SERVO_PULSE_MAX = 2000
SERVO_PERIOD = 20000

# ---------- UTILS ----------
def clamp(v, lo, hi): return lo if v < lo else hi if v > hi else v

def _area_closeness(area):
    a = clamp(area, MIN_AREA, MAX_AREA)
    frac = (a - MIN_AREA) / float(MAX_AREA - MIN_AREA + 1e-6)
    return pow(clamp(frac, 0.0, 1.0), AREA_RESPONSE_GAMMA)

def compute_servo_angle(color, area):
    w = _area_closeness(area)
    near = LEFT_NEAR if color == "Red" else RIGHT_NEAR
    raw = CENTER_ANGLE + AREA_GAIN * w * (near - CENTER_ANGLE)
    return int(round(clamp(raw, SERVO_MIN, SERVO_MAX)))

def get_largest_contour(mask, min_area=500):
    contours, _ = cv2.findContours(mask, cv2.RETR_EXTERNAL, cv2.CHAIN_APPROX_SIMPLE)
    if not contours:
        return None
    c = max(contours, key=cv2.contourArea)
    if cv2.contourArea(c) < min_area:
        return None
    x,y,w,h = cv2.boundingRect(c)
    return c, (x,y), (x+w, y+h), w*h

def boxes_intersect(a, b):
    ax1, ay1, ax2, ay2 = a
    bx1, by1, bx2, by2 = b
    return not (ax2 < bx1 or ax1 > bx2 or ay2 < by1 or ay1 > by2)

def imu_center_servo(yaw_deg):
    if abs(yaw_deg) <= YAW_DEADBAND_DEG:
        return CENTER_ANGLE
    corr = clamp(YAW_KP * yaw_deg, -SERVO_CORR_LIMIT, SERVO_CORR_LIMIT)
    return int(CENTER_ANGLE + corr)

def y_at_center(lines, center_x):
    if lines is None:
        return -1
    ys = []
    for x1,y1,x2,y2 in lines[:,0]:
        if x1 != x2:
            m = (y2 - y1) / float(x2 - x1)
            y = m * (center_x - x1) + y1
            ys.append(y)
        else:
            if x1 == center_x:
                ys.append(max(y1, y2))
    return max(ys) if ys else -1

def set_leds(red=False, green=False, blue=False):
    GPIO.output(LED_RED_PIN,   GPIO.HIGH if red else GPIO.LOW)
    GPIO.output(LED_GREEN_PIN, GPIO.HIGH if green else GPIO.LOW)
    GPIO.output(LED_BLUE_PIN,  GPIO.HIGH if blue else GPIO.LOW)

# ---------- HARDWARE INIT ----------
GPIO.setmode(GPIO.BCM)
for p in [LED_BLUE_PIN, LED_RED_PIN, LED_GREEN_PIN]:
    GPIO.setup(p, GPIO.OUT)
    GPIO.output(p, GPIO.LOW)

# Camera
picam2 = Picamera2()
picam2.configure(picam2.create_preview_configuration(main={"size": CAM_SIZE}))
picam2.start()
time.sleep(1.5)

# I2C + PCA9685 (same style as your script)
i2c = busio.I2C(board.SCL, board.SDA)
pca = PCA9685(i2c)
pca.frequency = 50
I2C_LOCK = threading.Lock()
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

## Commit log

2024-12-14 Rename Code files/Arduino C/arduino_1.ino to R-A_comms.ino
2025-04-12 Rename Αντίγραφο του Αντίγραφο του Screenshot_2024-11-23-17-26-48-552_com.instagram.android-edit.jpg to Diagram handwritten
2025-04-16 Add files via upload
    Motorbase
2025-04-17 Create standard motor
2025-04-17 Rename standard motor to standard motor.py
2025-04-26 Rename Robot Photos/diycoloursensor.jpg to Robot Photos/Robot sensors/diycoloursensor.jpg
2025-05-31 Rename 3d designs/3d printed motor gear.jpg to 3d designs/3d printed part photos/3d printed motor gear.jpg
2025-05-31 Rename 3d designs/3d printing process.jpg to 3d designs/3d printed part photos/3d printing process.jpg
2025-05-31 Rename 3d designs/Coloursensor3dprinted.jpg to 3d designs/3d printed part photos/Coloursensor3dprinted.jpg
2025-05-31 Rename 3d designs/Versions of Servo motor bases.jpg to 3d designs/3d printed part photos/Versions of Servo motor bases.jpg
2025-05-31 Rename 3d designs/base..stl to 3d designs/3d schematics/base..stl
    [base..stl]
2025-08-21 Create servo_test
2025-08-21 Create motor_test
2025-09-21 Rename newfirstmission_Iordanis_v2 to 1ST_mission_OptionA_Iordanis_v1
    Turn based on sensor readings
2025-09-24 Create imu
2025-09-28 Beta Version - use 4.91 in case of errors
2025-10-11 Rename Code files/Python files/New files September+/main.py to Code files/Python files/New files September+/stage_1/main.py
2025-10-11 Rename Code files/Python files/New files September+/stage_1/motor_servo.py to Code files/Python files/New files September+/stage_1/sensors/motor_servo.py
2025-10-11 Rename Code files/Python files/New files September+/stage_1/mpu6050.py to Code files/Python files/New files September+/stage_1/sensors/mpu6050.py
2025-10-11 Rename Code files/Python files/New files September+/stage_1/tof_sensors.py to Code files/Python files/New files September+/stage_1/sensors/tof_sensors.py
2025-10-11 Rename Code files/Python files/New files September+/stage_1/ultrasonic.py to Code files/Python files/New files September+/stage_1/sensors/ultrasonic.py
2025-10-11 Rename Code files/Python files/New files September+/stage_1/motor_servo.py to Code files/Python files/New files September+/stage_1/control/motor_servo.py
2025-10-16 Update README with camera limitations for turns
    Clarified limitations of camera setup for robot navigation.
2025-10-17 Add robotic control script with color detection
    This script initializes and controls a robotic system using a camera and IMU. It processes color detection and adjusts servo angles based on detected objects while maintaining motor control.
2025-10-17 Comment out Device.pin_factory initialization
    Comment out the Device.pin_factory initialization.
2025-10-17 Update print statement from 'Hello' to 'Goodbye'
2025-10-18 Create IMU turn.py
2025-10-18 Update IMU turn.py
2025-11-13 Refactor avoid-green-red.py for enhanced functionality
    Refactor and enhance the avoid-green-red.py script with improved constants, added emergency escape logic, and optimized servo control.
    [avoid-green-red.py]
2025-11-13 Change motor speed frequency from 1000 to 50 Hz
2025-11-13 Update and rename avoid-green-red.py to avoid-green-red2.py
    [avoid-green-red2.py]
2025-11-13 Refactor sensor data handling in test.py
    Removed unnecessary sensor tick wait and data processing code.
2025-11-17 Rename BOM.md to Materials needed and BOM.md
2025-11-17 Create Electronics-Power System.md
2025-11-18 Create Raspberry pi .md
2025-11-18 Update Electronics-Power System.md
2025-11-18 Update Raspberry pi .md
2025-11-20 3d designs
    [VLV-Tof-final.stl, VLV-camerabase-final.stl, VLV-chassis-final.stl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]
